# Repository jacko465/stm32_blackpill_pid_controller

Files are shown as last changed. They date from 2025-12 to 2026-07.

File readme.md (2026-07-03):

# STM32 Black Pill PID Motor Controller

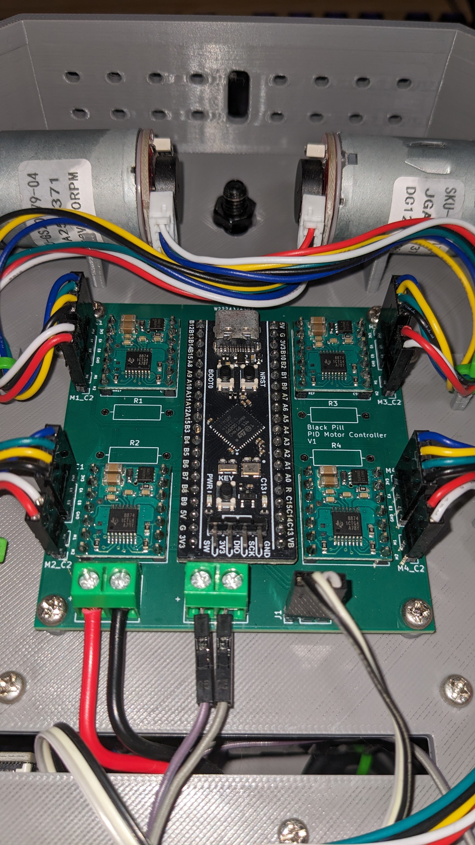
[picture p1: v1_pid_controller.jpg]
Example v1 PID controller deployment


*v1 deployment of the PID controller. With Pololu 4035 driver modules*

A PID-based motor control system for the STM32F411 Black Pill microcontroller, designed to control 4 DC motors with encoders via H-bridge drivers (e.g., TI DRV8874).

## Features

- **High-frequency PID control**: 1 kHz PID loop running on TIM10 interrupt
- **Encoder feedback**: 100 Hz encoder updates (quadrature decoding)
- **4 independent motor channels**: Each with PWM speed control and direction control
- **Configurable PID gains**: Kp, Ki, Kd parameters per motor
- **Anti-windup protection**: Integral clamping to prevent windup

## Hardware Configuration

### Motor Specifications
- Encoder: 11 PPR (basic) × 4 (quadrature) × 35.5 (gear ratio) = **1562 counts/revolution**
- PWM Frequency: Configured via TIM1 = 20kHz
- Control Loop: 1 ms update period (1 kHz)
- Encoder Reading: 10 ms update period (100 Hz)

### System Clock
- **84 MHz SYSCLK** derived from 25 MHz HSE crystal
- Configured with PLL (PLLM=25, PLLN=336, PLLP=4)

## Pinout

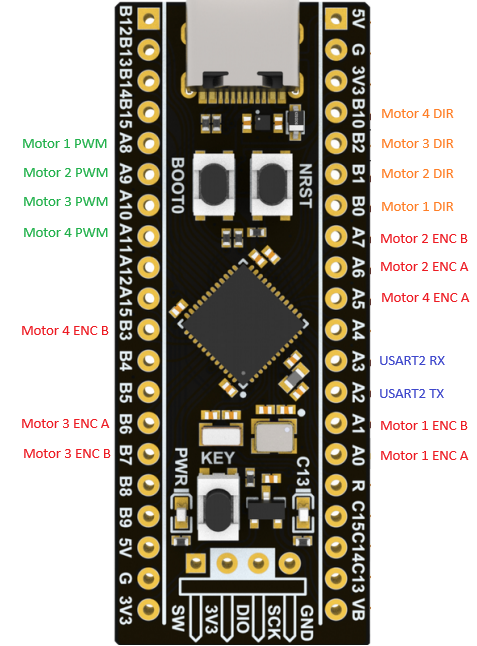
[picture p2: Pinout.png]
Pinout Diagram


| Function | Pin | Timer/Channel |
|---|-----|---|
| **Motor 1 PWM** | PA8 | TIM1 CH1 |
| **Motor 2 PWM** | PA9 | TIM1 CH2 |
| **Motor 3 PWM** | PA10 | TIM1 CH3 |
| **Motor 4 PWM** | PA11 | TIM1 CH4 |
| **Motor 1 DIR** | PB0 | GPIO |
| **Motor 2 DIR** | PB1 | GPIO |
| **Motor 3 DIR** | PB2 | GPIO |
| **Motor 4 DIR** | PB10 | GPIO |
| **Motor 1 Encoder A** | PA0 | TIM5 CH1 |
| **Motor 1 Encoder B** | PA1 | TIM5 CH2 |
| **Motor 2 Encoder A** | PA6 | TIM3 CH1 |
| **Motor 2 Encoder B** | PA7 | TIM3 CH2 |
| **Motor 3 Encoder A** | PB6 | TIM4 CH1 |
| **Motor 3 Encoder B** | PB7 | TIM4 CH2 |
| **Motor 4 Encoder A** | PA5 | TIM2 CH1 |
| **Motor 4 Encoder B** | PB3 | TIM2 CH2 |
| **USART2 TX** | PA2 | USART2 |
| **USART2 RX** | PA3 | USART2 |
| **LED** | PC13 | GPIO (onboard) |

## PID Configuration

Default PID gains (defined in [`motor.h`](include/motor.h)):
- **Kp**: 0.1
- **Ki**: 0.125
- **Kd**: 0.0
- **Integral Limit**: 5.0 (anti-windup)
- **Output Range**: -1.0 to 1.0 (bidirectional control)

## Motor Control Functions

This project has been coded for EN/PH driver control mode

The [`motor.c`](src/motor.c) module provides:
- `Motor_SetTargetRPM()`: Set target velocity in RPM
- `Motor_Forward()`: Drive motor forward with duty cycle
- `Motor_Reverse()`: Drive motor in reverse with duty cycle
- `Motor_Break()`: Active braking (both H-bridge outputs high)
- `Motor_Coast()`: Free-running coast (both outputs low)

## Building

This project uses **PlatformIO**. To build and upload

## Error Handling

The [`Error_Handler()`](src/main.c) function provides visual feedback via fast blinking of the onboard LED (PC13) if system initialization fails.

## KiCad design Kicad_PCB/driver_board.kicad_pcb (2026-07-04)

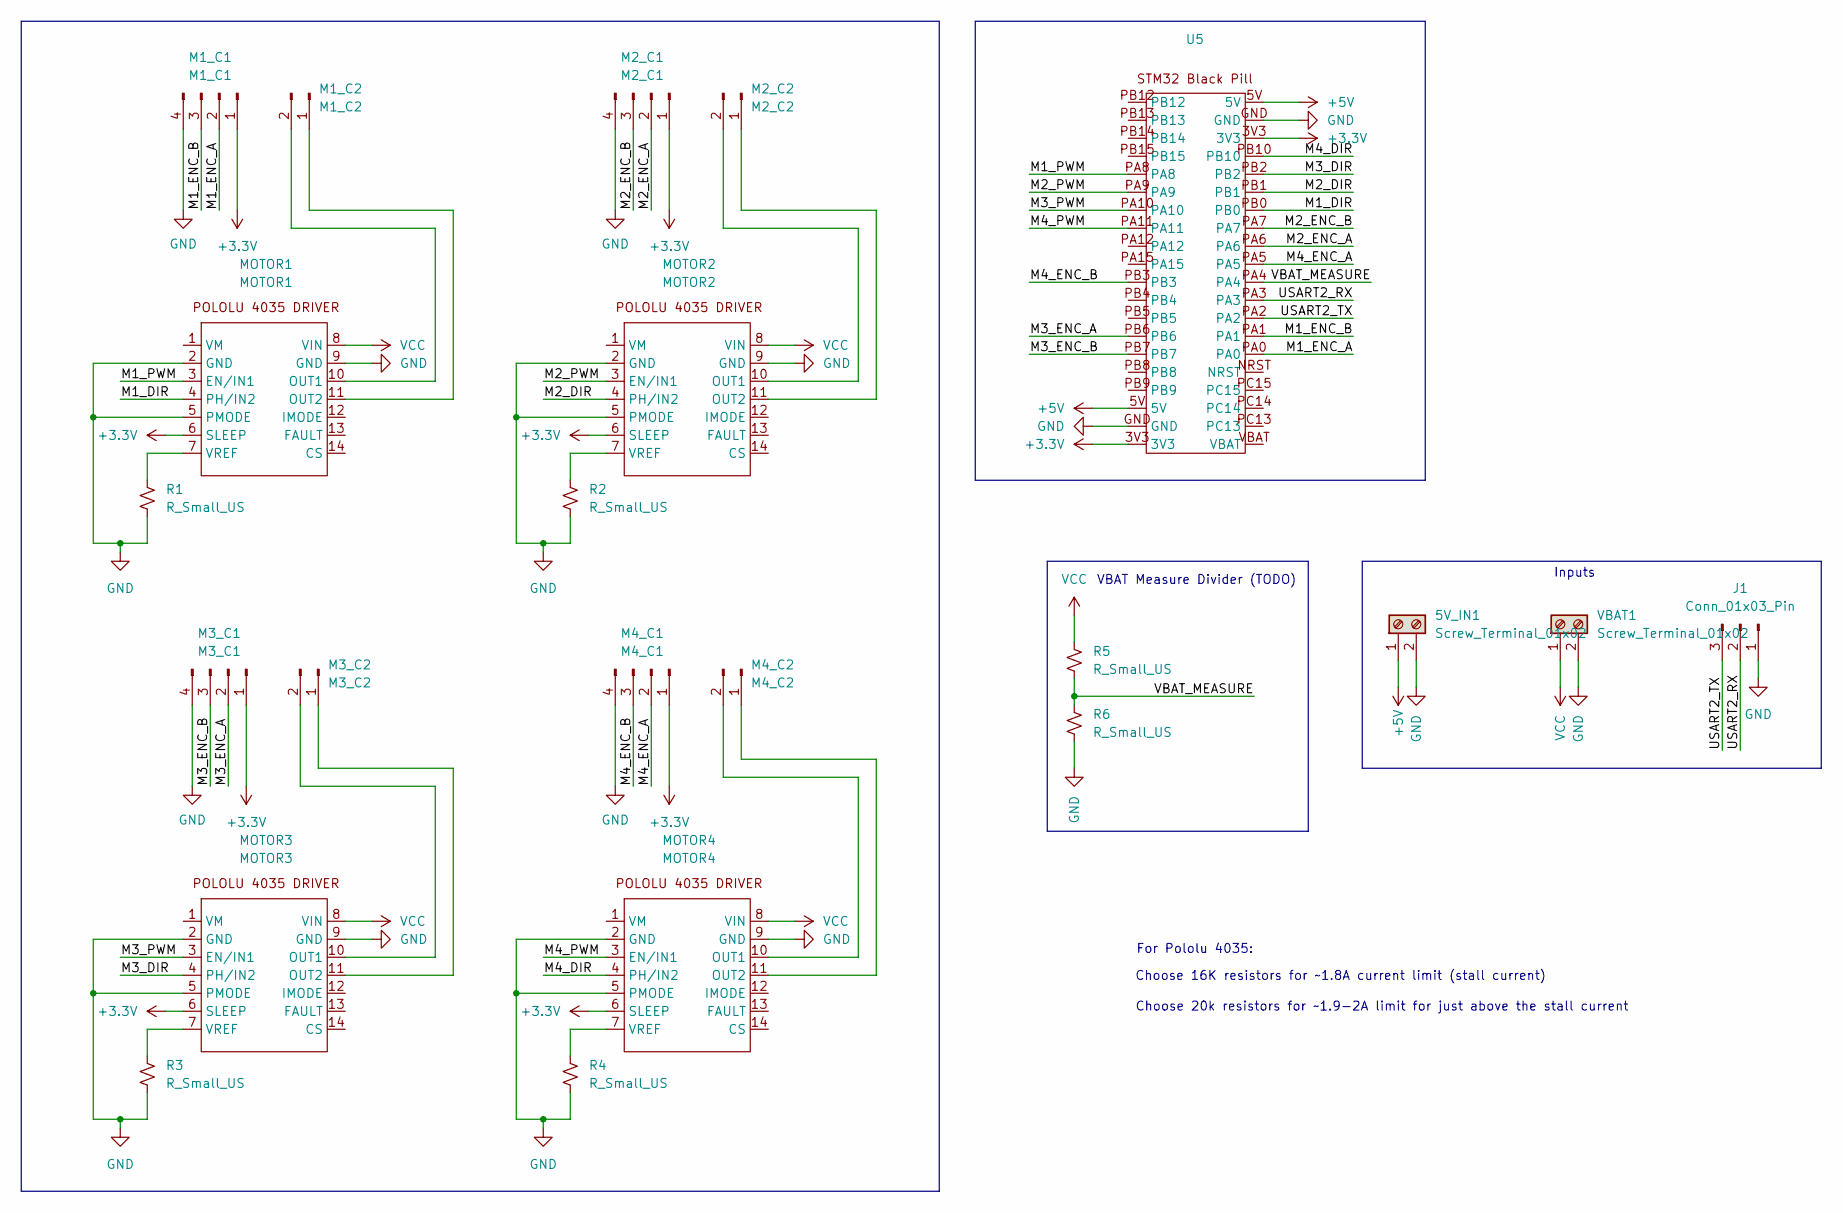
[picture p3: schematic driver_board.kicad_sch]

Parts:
5V_IN1: Screw_Terminal_01x02; TerminalBlock_MaiXu_MX126-5.0-02P_1x02_P5.00mm
J1: Conn_01x03_Pin; PinHeader_1x03_P2.54mm_Vertical
M1_C1: M1_C1; PinHeader_1x04_P2.54mm_Vertical
M1_C2: M1_C2; PinHeader_1x02_P2.54mm_Vertical
M2_C1: M2_C1; PinHeader_1x04_P2.54mm_Vertical
M2_C2: M2_C2; PinHeader_1x02_P2.54mm_Vertical
M3_C1: M3_C1; PinHeader_1x04_P2.54mm_Vertical
M3_C2: M3_C2; PinHeader_1x02_P2.54mm_Vertical
M4_C1: M4_C1; PinHeader_1x04_P2.54mm_Vertical
M4_C2: M4_C2; PinHeader_1x02_P2.54mm_Vertical
MOTOR1: MOTOR1; Pololu_4035_DRV8874_Motor_Driver
MOTOR2: MOTOR2; Pololu_4035_DRV8874_Motor_Driver
MOTOR3: MOTOR3; Pololu_4035_DRV8874_Motor_Driver
MOTOR4: MOTOR4; Pololu_4035_DRV8874_Motor_Driver
R1, R2, R3, R4, R5, R6: R_Small_US; R_Axial_DIN0309_L9.0mm_D3.2mm_P12.70mm_Horizontal
U5: STM32 Black Pill
VBAT1: Screw_Terminal_01x02; TerminalBlock_MaiXu_MX126-5.0-02P_1x02_P5.00mm

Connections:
+3.3V: M1_C1.1, M2_C1.1, M3_C1.1, M4_C1.1, MOTOR1.6 (SLEEP), MOTOR2.6 (SLEEP), MOTOR3.6 (SLEEP), MOTOR4.6 (SLEEP), U5.3V3
+5V: 5V_IN1.1, U5.5V
/M1_DIR: MOTOR1.4 (PH/IN2), U5.PB0
/M1_ENC_A: M1_C1.2, U5.PA0
/M1_ENC_B: M1_C1.3, U5.PA1
/M1_PWM: MOTOR1.3 (EN/IN1), U5.PA8
/M2_DIR: MOTOR2.4 (PH/IN2), U5.PB1
/M2_ENC_A: M2_C1.2, U5.PA6
/M2_ENC_B: M2_C1.3, U5.PA7
/M2_PWM: MOTOR2.3 (EN/IN1), U5.PA9
/M3_DIR: MOTOR3.4 (PH/IN2), U5.PB2
/M3_ENC_A: M3_C1.2, U5.PB6
/M3_ENC_B: M3_C1.3, U5.PB7
/M3_PWM: MOTOR3.3 (EN/IN1), U5.PA10
/M4_DIR: MOTOR4.4 (PH/IN2), U5.PB10
/M4_ENC_A: M4_C1.2, U5.PA5
/M4_ENC_B: M4_C1.3, U5.PB3
/M4_PWM: MOTOR4.3 (EN/IN1), U5.PA11
/USART2_RX: J1.2, U5.PA3
/USART2_TX: J1.3, U5.PA2
/VBAT_MEASURE: R5.2, R6.1, U5.PA4
GND: 5V_IN1.2, J1.1, M1_C1.4, M2_C1.4, M3_C1.4, M4_C1.4, MOTOR1.2 (GND), MOTOR1.5 (PMODE), MOTOR1.9 (GND), MOTOR2.2 (GND), MOTOR2.5 (PMODE), MOTOR2.9 (GND), MOTOR3.2 (GND), MOTOR3.5 (PMODE), MOTOR3.9 (GND), MOTOR4.2 (GND), MOTOR4.5 (PMODE), MOTOR4.9 (GND), R1.2, R2.2, R3.2, R4.2, R6.2, U5.GND, VBAT1.2
unnamed: M1_C2.1, MOTOR1.11 (OUT2)
unnamed: M1_C2.2, MOTOR1.10 (OUT1)
unnamed: M2_C2.1, MOTOR2.11 (OUT2)
unnamed: M2_C2.2, MOTOR2.10 (OUT1)
unnamed: M3_C2.1, MOTOR3.11 (OUT2)
unnamed: M3_C2.2, MOTOR3.10 (OUT1)
unnamed: M4_C2.1, MOTOR4.11 (OUT2)
unnamed: M4_C2.2, MOTOR4.10 (OUT1)
unnamed: MOTOR1.7 (VREF), R1.1
unnamed: MOTOR2.7 (VREF), R2.1
unnamed: MOTOR3.7 (VREF), R3.1
unnamed: MOTOR4.7 (VREF), R4.1
VCC: MOTOR1.8 (VIN), MOTOR2.8 (VIN), MOTOR3.8 (VIN), MOTOR4.8 (VIN), R5.1, VBAT1.1

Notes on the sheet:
VBAT Measure Divider (TODO)
Choose 20k resistors for ~1.9-2A limit for just above the stall current
Inputs
Choose 16K resistors for ~1.8A current limit (stall current)
For Pololu 4035:

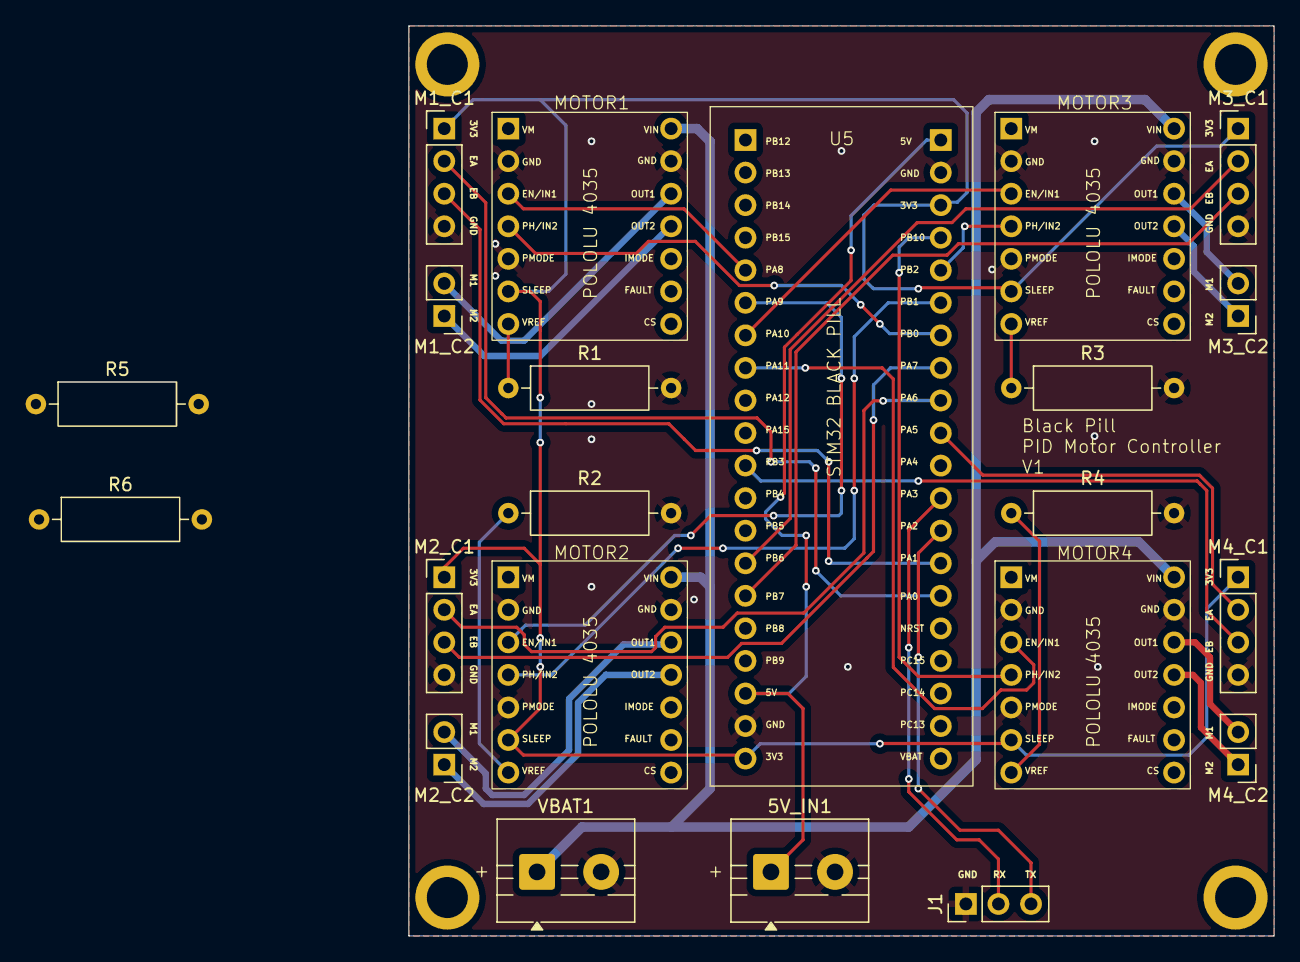
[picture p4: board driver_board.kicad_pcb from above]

Board: 2 copper layers, 67.5 x 71.0 mm, 22 parts (0 on the bottom side), 35 nets.

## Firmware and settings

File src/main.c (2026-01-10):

#include "main.h"
#include <string.h>
// #include <stdbool.h>
#include <stdlib.h>
// #include <stdint.h>

void SystemClock_Config(void);
uint8_t rx_dma_buf[RX_BUF_LEN]; // DMA RX buffer
static volatile uint16_t rx_old_pos = 0; // Old position in RX DMA buffer

static char line_buf[LINE_MAX];
static volatile uint16_t line_len = 0;

static volatile bool msg_ready = false;
static char msg_buf[LINE_MAX];

static uint32_t last_tel_ms = 0;
const uint32_t TEL_PERIOD_MS = 50;	// 20 Hz telemetry report rate
static uint32_t last_rx_ms = 0;

static void ProcessBytes(const uint8_t *data, uint16_t len);

int main(void)
{
	// Init HAL
	HAL_Init();

	// Configure the system clock
	SystemClock_Config();

	// Initialize all configured peripherals
	MX_GPIO_Init();
	MX_DMA_Init();		// DMA for USART2 RX
	MX_TIM1_Init();		// PWM timer
	MX_TIM2_Init();		// Encoder timer Motor 4
	MX_TIM3_Init();		// Encoder timer Motor 2
	MX_TIM4_Init();		// Encoder timer Motor 3
	MX_TIM5_Init();		// Encoder timer Motor 1
	MX_TIM10_Init();	// Interrupt timer for PID loop
	MX_USART2_UART_Init();	// Init USART2
	HAL_UART_Receive_DMA(&huart2, rx_dma_buf, RX_BUF_LEN); // Start USART2 RX in DMA mode
	__HAL_UART_ENABLE_IT(&huart2, UART_IT_IDLE); // Enable IDLE line interrupt for USART2

	// Start encoder timers
	HAL_TIM_Encoder_Start(&htim5, TIM_CHANNEL_ALL); // Motor 1 encoder
	HAL_TIM_Encoder_Start(&htim3, TIM_CHANNEL_ALL); // Motor 2 encoder
	HAL_TIM_Encoder_Start(&htim4, TIM_CHANNEL_ALL); // Motor 3 encoder
	HAL_TIM_Encoder_Start(&htim2, TIM_CHANNEL_ALL); // Motor 4 encoder

	// Start PWM timers
	HAL_TIM_PWM_Start(&htim1, TIM_CHANNEL_1); // Motor 1 PWM
	HAL_TIM_PWM_Start(&htim1, TIM_CHANNEL_2); // Motor 2 PWM
	HAL_TIM_PWM_Start(&htim1, TIM_CHANNEL_3); // Motor 3 PWM
	HAL_TIM_PWM_Start(&htim1, TIM_CHANNEL_4); // Motor 4 PWM

	// Start TIM10 interrupt timer (PID Loop)
	HAL_TIM_Base_Start_IT(&htim10);

	// Main loop
	while (1)
	{
		// Handle received USART messages
		uint32_t now = HAL_GetTick();
		if (msg_ready)
		{
			last_rx_ms = now;
			msg_ready = false;
			Handle_USART_Message();
		}
		else if (now - last_rx_ms >= LAST_RX_TIMEOUT_MS)
		{
			// No messages received for LAST_RX_TIMEOUT_MS -> stop motors
			Set_Left_RPM(0);
			Set_Right_RPM(0);
			// Disable_Motors();
		}

		// Report telemetry over serial every TEL_PERIOD_MS
		if (now - last_tel_ms >= TEL_PERIOD_MS)
		{
			last_tel_ms = now;
			Report_Telemetry_USART();
		}
	}
}

// Timer ISR callback
void HAL_TIM_PeriodElapsedCallback(TIM_HandleTypeDef *htim)
{
	// Counter for slower encoder updates
	static uint16_t encoder_update_counter = 0;

	if (htim->Instance == TIM10)
	{
		encoder_update_counter++;
		if (encoder_update_counter >= ENCODER_UPDATE_DIV)	// every ENCODER_UPDATE_DIV PID loops
		{
			encoder_update_counter = 0;
			// Update encoder readings
			Update_Motor_RPM(&motor1);
			Update_Motor_RPM(&motor2);
			Update_Motor_RPM(&motor3);
			Update_Motor_RPM(&motor4);
		}
		
		// PID control loop update
		PID_UpdateMotor(&motor1);
		PID_UpdateMotor(&motor2);
		PID_UpdateMotor(&motor3);
		PID_UpdateMotor(&motor4);
	}
}

// USART2 RX Idle ISR
void USART2_OnIdle(void)
{
    uint16_t new_pos = RX_BUF_LEN - __HAL_DMA_GET_COUNTER(huart2.hdmarx);
    if (new_pos == rx_old_pos) return;

    if (new_pos > rx_old_pos)
    {
        ProcessBytes(&rx_dma_buf[rx_old_pos], new_pos - rx_old_pos);
    }
    else
    {
        ProcessBytes(&rx_dma_buf[rx_old_pos], RX_BUF_LEN - rx_old_pos);
        if (new_pos > 0) ProcessBytes(&rx_dma_buf[0], new_pos);
    }

    rx_old_pos = new_pos;
}

// Process received bytes from USART2 DMA buffer
static void ProcessBytes(const uint8_t *data, uint16_t len)
{
    for (uint16_t i = 0; i < len; i++)
    {
        char c = (char)data[i];
        if (c == '\r') continue;

        if (c == '\n')
        {
			if (!msg_ready)
			{
				// finalize line
				uint16_t n = line_len;
				if (n >= LINE_MAX) n = LINE_MAX - 1;

				memcpy(msg_buf, line_buf, n);
				msg_buf[n] = '\0';

				line_len = 0;
				msg_ready = true;   // main loop will handle it
			}
			// else drop line – previous message not yet processed
        }
        else
        {
            if (line_len < LINE_MAX - 1)
                line_buf[line_len++] = c;
            else
                line_len = 0;   // overflow -> reset/drop
        }
    }
}

// Helper functions

static inline bool streq(const char *a, const char *b) { return strcmp(a,b) == 0; }

// Handle USART RX
void Handle_USART_Message(void)
{
	/* List of commands:
		SET,<LEFT_RPM>,<RIGHT_RPM>		- Set target RPMs for motors
		EN,<1|0>                     	- Enable or disable motors
		BRK,<1|0>                    	- Enable or disable motor braking
		ESTOP					   		- Emergency stop (disable motors, latches until controller restart)
		PING							- Check is alive
		PID,<P>,<I>,<D>            		- Set PID parameters for all motors
	*/
	if (ESTOP) return; // ignore all commands if ESTOP is set
	
	// Create null-terminated copy of msg_buf
	char line[LINE_MAX];
	strncpy(line, msg_buf, sizeof(line)-1);
	line[sizeof(line)-1] = '\0';

	// tokenise
	char *cmd = strtok(line, ",");
	char *a1 = strtok(NULL, ",");
	char *a2 = strtok(NULL, ",");
	// char *a3 = strtok(NULL, ",");
	
	if (!cmd) return;

	// SET,<LEFT_RPM>, <RIGHT_RPM>
	if (streq(cmd, "SET"))
	{
		int32_t l, r;
		if (parse_int32(a1, &l) && parse_int32(a2, &r))
		{
			Set_Left_RPM(l);
			Set_Right_RPM(r);
			uart_print("OK,SET\r\n");
		}
		else uart_print("ERR,BADARGS\r\n");
	}

	// EN,<1|0>
	else if (streq(cmd, "EN"))
	{
		int32_t en;
		if (parse_int32(a1, &en))
		{
			if (en) Enable_Motors();
			else Disable_Motors();
			uart_print("OK,EN\r\n");
		}
		else uart_print("ERR,BADARGS\r\n");
	}

	// BRK,<1|0>
	// else if (streq(cmd, "BRK"))
	// {
	// 	int32_t brk;
	// 	if (parse_int32(a1, &brk))
	// 	{
	// 		if (brk) Enable_Motor_Braking();
	// 		else Disable_Motor_Braking();
	// 		uart_print("OK\r\n");
	// 	}
	// 	else uart_print("ERR,BADARGS\r\n");
	// }

	// ESTOP
	else if (streq(cmd, "ESTOP"))
	{
		SET_ESTOP();
		uart_print("OK,ESTOP\r\n");
	}

	// PING
	else if (streq(cmd, "PING"))
	{
		if (a1)
		{
			char response[LINE_MAX];
			snprintf(response, sizeof(response), "PONG,%s\r\n", a1);
			uart_print(response);
		}
		else uart_print("PONG\r\n");
	}

	// PID
	// else if (streq(cmd, "PID"))
	// {
	// 	float p, i, d;
	// 	if (a1 && a2 && a3)
	// 	{
	// 		// not implemented yet
	// 	}
	// }
}

bool parse_int32(const char *str, int32_t *out_value)
{
	if (!str) return false;

	char *endptr = NULL;
	long val = strtol(str, &endptr, 10);
	if (endptr == str || *endptr != '\0') return false; // not clean integer
	*out_value = (int32_t)val;
	return true;
}

// Report status over USART
void Report_Telemetry_USART(void)
{
	// Telemetry format:
	// TEL,<motors_enabled>,<ESTOP>,<motor1_rpm>,<motor2_rpm>,<motor3_rpm>,<motor4_rpm>\r\n

	char buf[160];
	int n = snprintf(buf, sizeof(buf),
		"TEL,%u,%u,%d,%d,%d,%d\r\n",
		Motors_Enabled, ESTOP,
		(int)motor1.rpm, (int)motor2.rpm, (int)motor3.rpm, (int)motor4.rpm
	);

	if (n > 0)
	{
		// HAL_UART_Transmit(&huart2, (uint8_t*)buf, (uint16_t)n, 20);
		uart_print(buf);
	}
}

void uart_print(const char *str)
{
	HAL_UART_Transmit(&huart2, (uint8_t*)str, (uint16_t)strlen(str), 50);
}

// Get encoder count from timer
uint16_t Encoder_GetCount(TIM_HandleTypeDef *htim)
{
    return (uint16_t)__HAL_TIM_GET_COUNTER(htim);
}

// SET PWM duty cycle on TIM channels for motor control (DC 0.0 to 1.0)
void SET_PWM_DC(TIM_HandleTypeDef *htim, uint8_t timer_channel, float duty_cycle)
{
    if (duty_cycle < 0.0f) duty_cycle = 0.0f;
    if (duty_cycle > 1.0f) duty_cycle = 1.0f;

    uint32_t period = __HAL_TIM_GET_AUTORELOAD(htim);
    uint32_t ccr = (uint32_t)(duty_cycle * (period + 1));

    __HAL_TIM_SET_COMPARE(htim, timer_channel, ccr);
}

// System Clock Configuration 84 MHz SYSCLOCK with 25 MHz HSE
void SystemClock_Config(void)
{
	RCC_OscInitTypeDef RCC_OscInitStruct = {0};
	RCC_ClkInitTypeDef RCC_ClkInitStruct = {0};

	/** Configure the main internal regulator output voltage
	 */
	__HAL_RCC_PWR_CLK_ENABLE();
	__HAL_PWR_VOLTAGESCALING_CONFIG(PWR_REGULATOR_VOLTAGE_SCALE1);

	/** Initializes the RCC Oscillators according to the specified parameters
	 * in the RCC_OscInitTypeDef structure.
	 */
	RCC_OscInitStruct.OscillatorType = RCC_OSCILLATORTYPE_HSE;
	RCC_OscInitStruct.HSEState = RCC_HSE_ON;
	RCC_OscInitStruct.PLL.PLLState = RCC_PLL_ON;
	RCC_OscInitStruct.PLL.PLLSource = RCC_PLLSOURCE_HSE;
	RCC_OscInitStruct.PLL.PLLM = 25;
	RCC_OscInitStruct.PLL.PLLN = 336;
	RCC_OscInitStruct.PLL.PLLP = RCC_PLLP_DIV4;
	RCC_OscInitStruct.PLL.PLLQ = 4;
	if (HAL_RCC_OscConfig(&RCC_OscInitStruct) != HAL_OK)
	{
		Error_Handler();
	}

	/** Initializes the CPU, AHB and APB buses clocks
	 */
	RCC_ClkInitStruct.ClockType = RCC_CLOCKTYPE_HCLK|RCC_CLOCKTYPE_SYSCLK
								|RCC_CLOCKTYPE_PCLK1|RCC_CLOCKTYPE_PCLK2;
	RCC_ClkInitStruct.SYSCLKSource = RCC_SYSCLKSOURCE_PLLCLK;
	RCC_ClkInitStruct.AHBCLKDivider = RCC_SYSCLK_DIV1;
	RCC_ClkInitStruct.APB1CLKDivider = RCC_HCLK_DIV2;
	RCC_ClkInitStruct.APB2CLKDivider = RCC_HCLK_DIV1;

	if (HAL_RCC_ClockConfig(&RCC_ClkInitStruct, FLASH_LATENCY_2) != HAL_OK)
	{
		Error_Handler();
	}
}

// Error handler
void Error_Handler(void)
{
	__disable_irq();
	// Fast blink PC13 so you know the clock config (or something else) died
	__HAL_RCC_GPIOC_CLK_ENABLE();
	GPIO_InitTypeDef GPIO_InitStruct = {0};
	GPIO_InitStruct.Pin   = GPIO_PIN_13;
	GPIO_InitStruct.Mode  = GPIO_MODE_OUTPUT_PP;
	GPIO_InitStruct.Speed = GPIO_SPEED_FREQ_LOW;
	HAL_GPIO_Init(GPIOC, &GPIO_InitStruct);
	while (1)
	{
		HAL_GPIO_TogglePin(GPIOC, GPIO_PIN_13);
		for (volatile uint32_t i = 0; i < 500000; ++i) 
		{
			// crude delay
		}
	}
}

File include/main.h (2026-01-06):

#ifndef __MAIN_H
#define __MAIN_H

#ifdef __cplusplus
extern "C" {
#endif

#include <stdio.h>
#include "stm32f4xx_hal.h"
#include "motor.h"
#include "dma.h"
#include "tim.h"
#include "usart.h"
#include "gpio.h"
#include <stdbool.h>
#include <stdint.h>

// RX buffer for USART2 DMA
#define RX_BUF_LEN 256
#define LINE_MAX 128
extern uint8_t rx_dma_buf[RX_BUF_LEN]; // DMA RX buffer

#define LAST_RX_TIMEOUT_MS 200 // Timeout if no RX for 200 ms

// LOOP FREQUENCIES
#define PID_LOOP_FREQUENCY_HZ 1000.0f         // 1kHz PID loop
#define ENCODER_UPDATE_DIV 50                 // Update encoder reading every 50 PID loops
#define ENCODER_UPDATE_FREQUENCY_HZ (PID_LOOP_FREQUENCY_HZ / ENCODER_UPDATE_DIV)

#define PID_UPDATE_PERIOD (1.0f / PID_LOOP_FREQUENCY_HZ)
#define ENCODER_UPDATE_PERIOD (1.0f / ENCODER_UPDATE_FREQUENCY_HZ)

void Error_Handler(void);
uint16_t Encoder_GetCount(TIM_HandleTypeDef *htim);
void SET_PWM_DC(TIM_HandleTypeDef *htim, uint8_t timer_channel, float duty_cycle);
void USART2_OnIdle(void);
void Handle_USART_Message(void);
bool parse_int32(const char *str, int32_t *out_value);
void Report_Telemetry_USART(void);
void uart_print(const char *str);

#ifdef __cplusplus
}
#endif

#endif

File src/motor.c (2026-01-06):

#include "motor.h"

uint8_t Motors_Enabled = 0;
uint8_t ESTOP = 0;

// motor instances
Motor_t motor1 = {
    // Encoder state
    .prev_count = 0,
    .curr_count = 0,
    .rpm = 0.0f,
    .delta = 0,

    // Encoder timer pointer
    .htim_encoder = &htim5, // TIM5 (PA0/PA1) Motor 1 encoder

    //PID gains
    .kp = KP,
    .ki = KI,
    .kd = KD,

    // PID state
    .integral = 0.0f,
    .prev_error = 0.0f,
    .output = 0.0f,

    // Target
    .enabled = 0,
    .target_rpm = 0,
    .target_delta = 0,

    // Integral limit (anti-windup) 5x output clamp
    .integral_limit = PID_INTEGRAL_LIMIT,

    // Output limits
    .output_min = PID_OUTPUT_MIN,
    .output_max = PID_OUTPUT_MAX,

    // PWM output
    .htim_pwm = &htim1,                     // TIM1
    .pwm_channel = TIM_CHANNEL_1,           // PA8

    // DIR pin
    .dir_port = GPIOB,                      // PB0
    .dir_pin = GPIO_PIN_0                   // PB0
};

Motor_t motor2 = {
    // Encoder state
    .prev_count = 0,
    .curr_count = 0,
    .rpm = 0.0f,
    .delta = 0,

    // Encoder timer pointer
    .htim_encoder = &htim3, // TIM3 (PA6/PA7) Motor 2 encoder

    //PID gains
    .kp = KP,
    .ki = KI,
    .kd = KD,

    // PID state
    .integral = 0.0f,
    .prev_error = 0.0f,
    .output = 0.0f,

    // Target
    .enabled = 0,
    .target_rpm = 0,
    .target_delta = 0,

    // Integral limit (anti-windup) 5x output clamp
    .integral_limit = PID_INTEGRAL_LIMIT,

    // Output limits
    .output_min = PID_OUTPUT_MIN,
    .output_max = PID_OUTPUT_MAX,
    // PWM output
    .htim_pwm = &htim1,                     // TIM1
    .pwm_channel = TIM_CHANNEL_2,           // PA9

    // DIR pin
    .dir_port = GPIOB,                      // PB0
    .dir_pin = GPIO_PIN_1                   // PB1
};

Motor_t motor3 = {
    // Encoder state
    .prev_count = 0,
    .curr_count = 0,
    .rpm = 0.0f,
    .delta = 0,

    // Encoder timer pointer
    .htim_encoder = &htim4, // TIM4 (PB6/PB7) Motor 3 encoder

    //PID gains
    .kp = KP,
    .ki = KI,
    .kd = KD,

    // PID state
    .integral = 0.0f,
    .prev_error = 0.0f,
    .output = 0.0f,

    // Target
    .enabled = 0,
    .target_rpm = 0,
    .target_delta = 0,

    // Integral limit (anti-windup) 5x output clamp
    .integral_limit = PID_INTEGRAL_LIMIT,

    // Output limits
    .output_min = PID_OUTPUT_MIN,
    .output_max = PID_OUTPUT_MAX,
    // PWM output
    .htim_pwm = &htim1,                     // TIM1
    .pwm_channel = TIM_CHANNEL_3,           // PA10

    // DIR pin
    .dir_port = GPIOB,                      // PB0
    .dir_pin = GPIO_PIN_2                   // PB2
};

Motor_t motor4 = {
    // Encoder state
    .prev_count = 0,
    .curr_count = 0,
    .rpm = 0.0f,
    .delta = 0,

    // Encoder timer pointer
    .htim_encoder = &htim2, // TIM2 (PA0/PA1) Motor 4 encoder

    //PID gains
    .kp = KP,
    .ki = KI,
    .kd = KD,

    // PID state
    .integral = 0.0f,
    .prev_error = 0.0f,
    .output = 0.0f,

    // Target
    .enabled = 0,
    .target_rpm = 0,
    .target_delta = 0,

    // Integral limit (anti-windup) 5x output clamp
    .integral_limit = PID_INTEGRAL_LIMIT,

    // Output limits
    .output_min = PID_OUTPUT_MIN,
    .output_max = PID_OUTPUT_MAX,
    // PWM output
    .htim_pwm = &htim1,                     // TIM1
    .pwm_channel = TIM_CHANNEL_4,           // PA11

    // DIR pin
    .dir_port = GPIOB,                      // PB0
    .dir_pin = GPIO_PIN_10                  // PB10
};

// PID Loop function
void PID_UpdateMotor(Motor_t *motor)
{
    if (!motor->enabled)
    {
        Motor_Break(motor);
        return;
    }

    // Compute error terms
    // float error = (float)motor->target_delta - (float)(motor->delta);
    float error = motor->target_delta - (float)(motor->delta);
    motor->integral += error * PID_UPDATE_PERIOD;
    float derivative = (error - motor->prev_error) / PID_UPDATE_PERIOD;
    motor->prev_error = error;

    // Clamp integral to prevent windup
    if (motor->integral > motor->integral_limit) motor->integral = motor->integral_limit;
    if (motor->integral < -motor->integral_limit) motor->integral = -motor->integral_limit;

    // Compute PID
    motor->output = (motor->kp * error) + (motor->ki * motor->integral) + (motor->kd * derivative);

    // Clamp output
    if (motor->output > motor->output_max) motor->output = motor->output_max;
    if (motor->output < motor->output_min) motor->output = motor->output_min;

    // Apply output to motor
    Motor_ApplyOutput(motor);
}

// Update motor velocity (call every ~10ms)
void Update_Motor_RPM(Motor_t *motor)
{
    motor->prev_count = motor->curr_count;
    motor->curr_count = Encoder_GetCount(motor->htim_encoder);
    motor->delta = (int16_t)(motor->curr_count - motor->prev_count);
    float counts_per_sec = motor->delta * ENCODER_UPDATE_FREQUENCY_HZ;
    motor->rpm = counts_per_sec * 60.0f / ENCODER_COUNTS_PER_REV;
}

// Set motor RPM target
void Motor_SetTargetRPM(Motor_t *motor, int32_t target_rpm)
{
    motor->target_rpm = target_rpm;
    motor->target_delta = target_rpm * ((float)ENCODER_COUNTS_PER_REV / 60.0f) * ENCODER_UPDATE_PERIOD;
}

void Enable_Motors(void)
{
    Motors_Enabled = 1;
    motor1.enabled = 1;
    motor2.enabled = 1;
    motor3.enabled = 1;
    motor4.enabled = 1;
}

void Disable_Motors(void)
{
    Motors_Enabled = 0;
    motor1.enabled = 0;
    motor2.enabled = 0;
    motor3.enabled = 0;
    motor4.enabled = 0;
}

void SET_ESTOP(void)
{
    ESTOP = 1;
    Set_Left_RPM(0);
    Set_Right_RPM(0);
    Disable_Motors();
}

// motor driving methods

// Motor apply output (set by PID)
void Motor_ApplyOutput(Motor_t *motor)
{
    float duty_cycle = motor->output;
    if (duty_cycle > 0.0f)
    {
        Motor_Forward(motor, duty_cycle);
    }
    else if (duty_cycle < 0.0f)
    {
        Motor_Reverse(motor, -duty_cycle);
    }
    else
    {
        Motor_Break(motor);
    }
}

// Motor break function
void Motor_Break(Motor_t *motor)
{
    SET_PWM_DC(motor->htim_pwm, motor->pwm_channel, 0.0f);
    HAL_GPIO_WritePin(motor->dir_port, motor->dir_pin, GPIO_PIN_SET);
}

// Motor coast function (pololu 4035 does not support coasting in ph/en mode)
// void Motor_Coast(Motor_t *motor)
// {
//     SET_PWM_DC(motor->htim_pwm, motor->pwm_channel, 0.0f);
//     HAL_GPIO_WritePin(motor->dir_port, motor->dir_pin, GPIO_PIN_RESET);
// }

// Basic motor forward function
void Motor_Forward(Motor_t *motor, float duty_cycle)
{
    SET_PWM_DC(motor->htim_pwm, motor->pwm_channel, duty_cycle);
    HAL_GPIO_WritePin(motor->dir_port, motor->dir_pin, GPIO_PIN_RESET);
}

// Basic motor reverse function
void Motor_Reverse(Motor_t *motor, float duty_cycle)
{
    SET_PWM_DC(motor->htim_pwm, motor->pwm_channel, duty_cycle);
    HAL_GPIO_WritePin(motor->dir_port, motor->dir_pin, GPIO_PIN_SET);
}

// Skid steer functions
void Set_Left_RPM(int32_t rpm)
{
    Motor_SetTargetRPM(&motor1, rpm);
    Motor_SetTargetRPM(&motor2, rpm);
}
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

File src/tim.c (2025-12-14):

#include "tim.h"

TIM_HandleTypeDef htim1;
TIM_HandleTypeDef htim2;
TIM_HandleTypeDef htim3;
TIM_HandleTypeDef htim4;
TIM_HandleTypeDef htim5;
TIM_HandleTypeDef htim10;

/* TIM1 init function */
void MX_TIM1_Init(void)
{

	TIM_MasterConfigTypeDef sMasterConfig = {0};
	TIM_OC_InitTypeDef sConfigOC = {0};
	TIM_BreakDeadTimeConfigTypeDef sBreakDeadTimeConfig = {0};

	htim1.Instance = TIM1;
	htim1.Init.Prescaler = 0;
	htim1.Init.CounterMode = TIM_COUNTERMODE_UP;
	htim1.Init.Period = 4199;
	htim1.Init.ClockDivision = TIM_CLOCKDIVISION_DIV1;
	htim1.Init.RepetitionCounter = 0;
	htim1.Init.AutoReloadPreload = TIM_AUTORELOAD_PRELOAD_ENABLE;
	if (HAL_TIM_PWM_Init(&htim1) != HAL_OK)
	{
		Error_Handler();
	}
	sMasterConfig.MasterOutputTrigger = TIM_TRGO_RESET;
	sMasterConfig.MasterSlaveMode = TIM_MASTERSLAVEMODE_DISABLE;
	if (HAL_TIMEx_MasterConfigSynchronization(&htim1, &sMasterConfig) != HAL_OK)
	{
		Error_Handler();
	}
	sConfigOC.OCMode = TIM_OCMODE_PWM1;
	sConfigOC.Pulse = 0;
	sConfigOC.OCPolarity = TIM_OCPOLARITY_HIGH;
	sConfigOC.OCNPolarity = TIM_OCNPOLARITY_HIGH;
	sConfigOC.OCFastMode = TIM_OCFAST_DISABLE;
	sConfigOC.OCIdleState = TIM_OCIDLESTATE_RESET;
	sConfigOC.OCNIdleState = TIM_OCNIDLESTATE_RESET;
	if (HAL_TIM_PWM_ConfigChannel(&htim1, &sConfigOC, TIM_CHANNEL_1) != HAL_OK)
	{
		Error_Handler();
	}
	if (HAL_TIM_PWM_ConfigChannel(&htim1, &sConfigOC, TIM_CHANNEL_2) != HAL_OK)
	{
		Error_Handler();
	}
	if (HAL_TIM_PWM_ConfigChannel(&htim1, &sConfigOC, TIM_CHANNEL_3) != HAL_OK)
	{
		Error_Handler();
	}
	if (HAL_TIM_PWM_ConfigChannel(&htim1, &sConfigOC, TIM_CHANNEL_4) != HAL_OK)
	{
		Error_Handler();
	}
	sBreakDeadTimeConfig.OffStateRunMode = TIM_OSSR_DISABLE;
	sBreakDeadTimeConfig.OffStateIDLEMode = TIM_OSSI_DISABLE;
	sBreakDeadTimeConfig.LockLevel = TIM_LOCKLEVEL_OFF;
	sBreakDeadTimeConfig.DeadTime = 0;
	sBreakDeadTimeConfig.BreakState = TIM_BREAK_DISABLE;
	sBreakDeadTimeConfig.BreakPolarity = TIM_BREAKPOLARITY_HIGH;
	sBreakDeadTimeConfig.AutomaticOutput = TIM_AUTOMATICOUTPUT_DISABLE;
	if (HAL_TIMEx_ConfigBreakDeadTime(&htim1, &sBreakDeadTimeConfig) != HAL_OK)
	{
		Error_Handler();
	}
	HAL_TIM_MspPostInit(&htim1);

}
/* TIM2 init function */
void MX_TIM2_Init(void)
{

	TIM_Encoder_InitTypeDef sConfig = {0};
	TIM_MasterConfigTypeDef sMasterConfig = {0};

	htim2.Instance = TIM2;
	htim2.Init.Prescaler = 0;
	htim2.Init.CounterMode = TIM_COUNTERMODE_UP;
	htim2.Init.Period = 4294967295;
	htim2.Init.ClockDivision = TIM_CLOCKDIVISION_DIV1;
	htim2.Init.AutoReloadPreload = TIM_AUTORELOAD_PRELOAD_DISABLE;
	sConfig.EncoderMode = TIM_ENCODERMODE_TI2;
	sConfig.IC1Polarity = TIM_ICPOLARITY_RISING;
	sConfig.IC1Selection = TIM_ICSELECTION_DIRECTTI;
	sConfig.IC1Prescaler = TIM_ICPSC_DIV1;
	sConfig.IC1Filter = 2;
	sConfig.IC2Polarity = TIM_ICPOLARITY_RISING;
	sConfig.IC2Selection = TIM_ICSELECTION_DIRECTTI;
	sConfig.IC2Prescaler = TIM_ICPSC_DIV1;
	sConfig.IC2Filter = 0;
	if (HAL_TIM_Encoder_Init(&htim2, &sConfig) != HAL_OK)
	{
		Error_Handler();
	}
	sMasterConfig.MasterOutputTrigger = TIM_TRGO_RESET;
	sMasterConfig.MasterSlaveMode = TIM_MASTERSLAVEMODE_DISABLE;
	if (HAL_TIMEx_MasterConfigSynchronization(&htim2, &sMasterConfig) != HAL_OK)
	{
		Error_Handler();
	}
}
/* TIM3 init function */
void MX_TIM3_Init(void)
{

	TIM_Encoder_InitTypeDef sConfig = {0};
	TIM_MasterConfigTypeDef sMasterConfig = {0};

	htim3.Instance = TIM3;
	htim3.Init.Prescaler = 0;
	htim3.Init.CounterMode = TIM_COUNTERMODE_UP;
	htim3.Init.Period = 65535;
	htim3.Init.ClockDivision = TIM_CLOCKDIVISION_DIV1;
	htim3.Init.AutoReloadPreload = TIM_AUTORELOAD_PRELOAD_DISABLE;
	sConfig.EncoderMode = TIM_ENCODERMODE_TI2;
	sConfig.IC1Polarity = TIM_ICPOLARITY_RISING;
	sConfig.IC1Selection = TIM_ICSELECTION_DIRECTTI;
	sConfig.IC1Prescaler = TIM_ICPSC_DIV1;
	sConfig.IC1Filter = 2;
	sConfig.IC2Polarity = TIM_ICPOLARITY_RISING;
	sConfig.IC2Selection = TIM_ICSELECTION_DIRECTTI;
	sConfig.IC2Prescaler = TIM_ICPSC_DIV1;
	sConfig.IC2Filter = 0;
	if (HAL_TIM_Encoder_Init(&htim3, &sConfig) != HAL_OK)
	{
		Error_Handler();
	}
	sMasterConfig.MasterOutputTrigger = TIM_TRGO_RESET;
	sMasterConfig.MasterSlaveMode = TIM_MASTERSLAVEMODE_DISABLE;
	if (HAL_TIMEx_MasterConfigSynchronization(&htim3, &sMasterConfig) != HAL_OK)
	{
		Error_Handler();
	}
}
/* TIM4 init function */
void MX_TIM4_Init(void)
{

	TIM_Encoder_InitTypeDef sConfig = {0};
	TIM_MasterConfigTypeDef sMasterConfig = {0};

	htim4.Instance = TIM4;
	htim4.Init.Prescaler = 0;
	htim4.Init.CounterMode = TIM_COUNTERMODE_UP;
	htim4.Init.Period = 65535;
	htim4.Init.ClockDivision = TIM_CLOCKDIVISION_DIV1;
	htim4.Init.AutoReloadPreload = TIM_AUTORELOAD_PRELOAD_DISABLE;
	sConfig.EncoderMode = TIM_ENCODERMODE_TI2;
	sConfig.IC1Polarity = TIM_ICPOLARITY_RISING;
	sConfig.IC1Selection = TIM_ICSELECTION_DIRECTTI;
	sConfig.IC1Prescaler = TIM_ICPSC_DIV1;
	sConfig.IC1Filter = 2;
	sConfig.IC2Polarity = TIM_ICPOLARITY_RISING;
	sConfig.IC2Selection = TIM_ICSELECTION_DIRECTTI;
	sConfig.IC2Prescaler = TIM_ICPSC_DIV1;
	sConfig.IC2Filter = 0;
	if (HAL_TIM_Encoder_Init(&htim4, &sConfig) != HAL_OK)
	{
		Error_Handler();
	}
	sMasterConfig.MasterOutputTrigger = TIM_TRGO_RESET;
	sMasterConfig.MasterSlaveMode = TIM_MASTERSLAVEMODE_DISABLE;
	if (HAL_TIMEx_MasterConfigSynchronization(&htim4, &sMasterConfig) != HAL_OK)
	{
		Error_Handler();
	}
}
/* TIM5 init function */
void MX_TIM5_Init(void)
{

	TIM_Encoder_InitTypeDef sConfig = {0};
	TIM_MasterConfigTypeDef sMasterConfig = {0};

	htim5.Instance = TIM5;
	htim5.Init.Prescaler = 0;
	htim5.Init.CounterMode = TIM_COUNTERMODE_UP;
	htim5.Init.Period = 4294967295;
	htim5.Init.ClockDivision = TIM_CLOCKDIVISION_DIV1;
	htim5.Init.AutoReloadPreload = TIM_AUTORELOAD_PRELOAD_DISABLE;
	sConfig.EncoderMode = TIM_ENCODERMODE_TI2;
	sConfig.IC1Polarity = TIM_ICPOLARITY_RISING;
	sConfig.IC1Selection = TIM_ICSELECTION_DIRECTTI;
	sConfig.IC1Prescaler = TIM_ICPSC_DIV1;
	sConfig.IC1Filter = 2;
	sConfig.IC2Polarity = TIM_ICPOLARITY_RISING;
	sConfig.IC2Selection = TIM_ICSELECTION_DIRECTTI;
	sConfig.IC2Prescaler = TIM_ICPSC_DIV1;
	sConfig.IC2Filter = 0;
	if (HAL_TIM_Encoder_Init(&htim5, &sConfig) != HAL_OK)
	{
		Error_Handler();
	}
	sMasterConfig.MasterOutputTrigger = TIM_TRGO_RESET;
	sMasterConfig.MasterSlaveMode = TIM_MASTERSLAVEMODE_DISABLE;
	if (HAL_TIMEx_MasterConfigSynchronization(&htim5, &sMasterConfig) != HAL_OK)
	{
		Error_Handler();
	}
}
/* TIM10 init function */
void MX_TIM10_Init(void)
{

	htim10.Instance = TIM10;
	htim10.Init.Prescaler = 8399;
	htim10.Init.CounterMode = TIM_COUNTERMODE_UP;
	htim10.Init.Period = 9;
	htim10.Init.ClockDivision = TIM_CLOCKDIVISION_DIV1;
	htim10.Init.AutoReloadPreload = TIM_AUTORELOAD_PRELOAD_DISABLE;
	if (HAL_TIM_Base_Init(&htim10) != HAL_OK)
	{
		Error_Handler();
	}
}

void HAL_TIM_PWM_MspInit(TIM_HandleTypeDef* tim_pwmHandle)
{

	if(tim_pwmHandle->Instance==TIM1)
	{
		/* TIM1 clock enable */
		__HAL_RCC_TIM1_CLK_ENABLE();

		/* TIM1 interrupt Init */
		HAL_NVIC_SetPriority(TIM1_UP_TIM10_IRQn, 0, 0);
		HAL_NVIC_EnableIRQ(TIM1_UP_TIM10_IRQn);
	}
}
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

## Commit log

2025-12-14 code ported from stm32 blue pill controller, not fully implemented yet. Sanity check blink running on ISR working.
2025-12-14 changed a motor dir pin, added readme
2025-12-16 set new motor and encoder params, enabled hardware float on mcu
2025-12-16 created other motor variables and enabled them in main
2025-12-16 changed some variable declarations inside Motor_t to be volatile
2025-12-17 created default pid output limits and anti windup integral limit definitions
2025-12-17 added usart dma scaffolding
2025-12-17 more usart2 rx dma and idle isr scaffolding
2026-01-01 base code working for the stm32 black pill and pololu 4035 drivers
2026-01-03 PID tuned and parameters set for PID on target delta (for slam bot testing)
2026-01-05 added motor enable/disable and skid steer methods
2026-01-06 fixed bug where motor4 negative values broke it
    [gpio.c]
2026-01-06 changed some comms to make things more reliable finished basic motor testing via comms
2026-01-10 changed serial port in motor test
2026-04-28 added configured pwm frequency in readme
2026-07-04 Added Kicad project for blackpill and pololu 4035 driver modules
    [driver_board.kicad_pcb, driver_board.kicad_sch]
2026-07-04 changed kicad lib nicknames to properly link them to project symbols
